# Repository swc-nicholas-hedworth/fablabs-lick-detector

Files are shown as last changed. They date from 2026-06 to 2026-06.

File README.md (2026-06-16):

# Fablabs Lick Detector

Inspired by the Allen Institute's: https://github.com/AllenNeuralDynamics/harp.device.lickety-split

## 1. Introduction

Capacitive lick detection offer advantages in the accuracy and speed of lick/touch detection. The challenge comes when using it with ephys devices such as the neuropixel which can pickup the input signal from the touch detector as noise. Our lick detector was inspired by the Allen Institutes lick detector which is shown to have low impact on ephys recordings.

The goals for this device were as follows:
- Reliable lick detection
- Low noise on ephys readings
- Simple to adjust and debug
- Easy to manufacture
- Easy to adapt into your own design

## 2. Setup
### Power Supply Requirements
- Min. Voltage = 3V
- Max. Voltage = 5.5V
- Max Current Consumption = 70mA (regardless of input voltage).

The output TTL depends on the input VCC voltage. For example:
- If VCC = 3.3V, output TTL amplitude = 3.3V
- If VCC = 5V, output TTL amplitude = 5V

### Ground Connection
Although not strictly necessary, it is encouraged for the mouse to have a reference to the board's ground potential. Basically the mouse needs to touch a conductor which is connected to the board's 

#### Metalic Floor
if the floor the mouse stands on is conductive, you may connect this floor to the ground potential.

#### Ephys
If the mouse has an implanted ephys device, it is posssible to connect the board's ground to that of the implant's ground.

### Spout Connection
Using crocodile clip

## 3. Calibration

This section outlines how to set the positions of the potentiometers RV1 and RV2 without any specialised equipment.

If any steps do not work, see the debugging guide.

### Step 0: Theory
RV1 is used to set the oscillators gain. clockwise increases the gain. The goal is to have the gain as low as possible to produce a low amplitude and clean signal to the spout so as to not intefere with ephys measurements. At maximum gain the signal will be distorted, introducing harmonics to the signal which is undesireable. At a certain "minimum" gain the oscillator will stop working. The goal is to have the oscillator just turn on, this gives us the lowest circuit noise.

RV2 is used to set the output gain. clockwise increases the gain. The goal is to have gain as low as possible to achieve extremely fast response to lick events. The output signal goes through a schmitt trigger, ensuring the gain sets the output at just the point the schmitt trigger activates ensures the quickest response times.

### Step 1: Initial conditions
- Turn RV1 all the way clockwise. (max oscillator gain)
- Turn RV2 all the way anticlockwise (min output gain)

This condition ensures that the oscillator is working (although distorted) and that the LED is on.

### Step 2: Detection
- Turn RV2 clockwise until the LED turns off.

You should see the LED turn on when you touch the "SPOUT" pin, and turn back off when you stop touching

### Step 3: Refine
**The following steps reduce the amplitude of the oscillator, thereby giving lower noise to ephys measurements.**

- Turn RV1 anticlockwise until the LED turns on.
- Turn RV2 clockwise until the LED turns back off.
- Test that touching the "SPOUT" pin still turns the LED on.

### Step 4: Repeat

- Repeat Step 3 until the LED seizes to turn off or if the LED starts behaving weirdly.
- When you reach the point that the LED starts behaving weirdly, revert RV1 and RV2 back to the previous state when the LED was still operating successfully.

## 4. Test Results

This section is intended to show the typical performance of the lick detector at each test point, showing how individual parts of the circuit should perform under normal conditions.

A Keysight DSOX1204A was used to capture the waveform and calculate the FFT. A custom BNC to pin header cable was created to feed signals from the board to the oscilloscope.

### [VCC] Input Voltage
The input voltage is used to power the dual supply converter on the board and the output stage op-amp (see amp and TTL test points).

### [V+] Positive Voltage Rail
This supply rail is generated by the dual supply converter.

### [V-] Negative Voltage Rail
This supply rail is generated by the dual supply converter.

### [osc] Oscillator

### [out] Signal to Spout

### [buf] Buffered Signal from Spout

### [hwr] Half Wave Rectifier

### [pfwr] Precision Full Wave Rectifier

### [lpf] Low-Pass Filter

### [amp] Amplifier 

### [TTL] Final Output TTL

### 5. EMI Performance

This section focuses on how the lick detectors near field noise looks like.

#### E-Field

#### H-Field

### 6. Impact on Ephys Recordings

This section evaluates the impact of noise on Ephys Recordings.

A mouse will lick from a spout. We will collect the following readings:
1. **Control**: 
2. **Grounded to Ephys**:
3. **Grounded to Ephys and Conductive Floor**:

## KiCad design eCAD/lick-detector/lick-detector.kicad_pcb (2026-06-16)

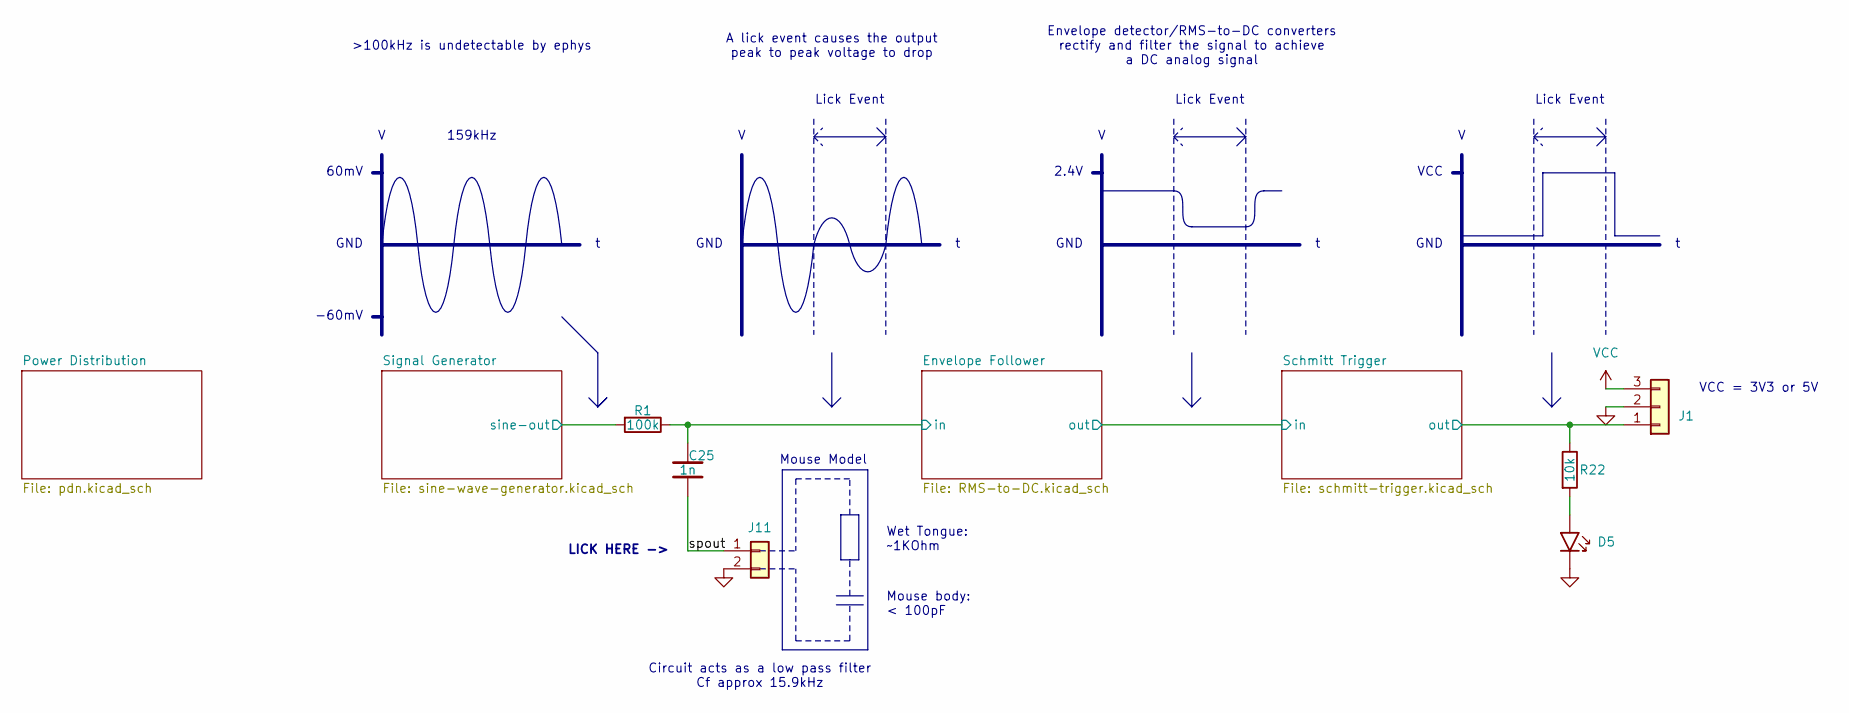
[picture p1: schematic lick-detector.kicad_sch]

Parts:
C25: 1n; C_0603_1608M; Part Version 0.0.0; JLCPCB Part # C1588
D5: !LED; LED_0805_2012M; Part Version 0.0.0; JLCPCB Part # C2297
J1: J_PinHeader_01x03_2.54_V; MFR.Part # PZ254V-11-03P; JLCPCB Part # C2937625
J11: J_PinHeader_01x02_2.54_V; MFR.Part # PZ254V-11-02P; JLCPCB Part # C492401
R1: 100k; R_0603_1608M; Part Version 0.0.0; JLCPCB Part # C25803
R22: 10k; R_0603_1608M; Part Version 0.0.0; JLCPCB Part # C25804

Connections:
/RMS-to-DC/in: C25.2, R1.2; also elsewhere on the board
/schmitt-trigger/out: J1.1, R22.2; also elsewhere on the board
/sine-wave-generator/out: R1.1; also elsewhere on the board
/spout: C25.1, J11.1
GND: D5.1 (K), J1.2, J11.2; also elsewhere on the board
unnamed: D5.2 (A), R22.1
VCC: J1.3; also elsewhere on the board

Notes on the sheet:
Lick Event
VCC
A lick event causes the output peak to peak voltage to drop
159kHz
GND
2.4V
>100kHz is undetectable by ephys
Wet Tongue: ~1KOhm
Mouse Model
-60mV
Envelope detector/RMS-to-DC converters rectify and filter the signal to achieve a DC analog signal
LICK HERE ->
VCC = 3V3 or 5V
Mouse body: < 100pF
Circuit acts as a low pass filter Cf approx 15.9kHz
60mV

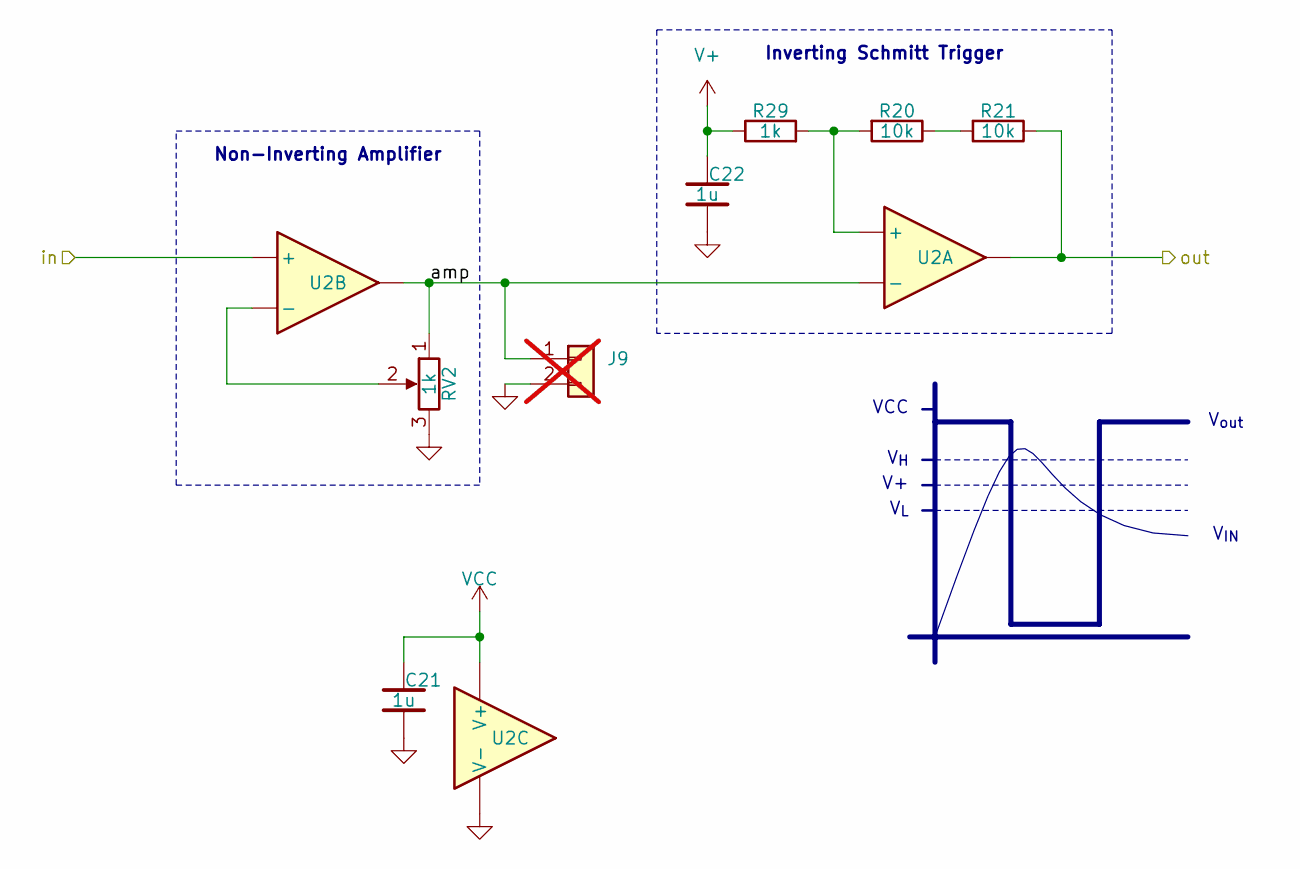
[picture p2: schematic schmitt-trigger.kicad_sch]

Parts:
C21, C22: 1u; C_0603_1608M; Part Version 0.0.0; JLCPCB Part # C15849
J9: J_PinHeader_01x02_2.54_V; MFR.Part # PZ254V-11-02P; JLCPCB Part # C492401; not fitted
R20, R21: 10k; R_0603_1608M; Part Version 0.0.0; JLCPCB Part # C25804
R29: 1k; R_0603_1608M; Part Version 0.0.0; JLCPCB Part # C22962
RV2: 1k; 3314J-1-102E; Part Version 0.0.0; JLCPCB Part # C124640
U2: OPA2365; SOIC-8_3.9x4.9mm; Part Version 0.0.0; JLCPCB Part # C130011

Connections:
/RMS-to-DC/lpf: U2.5 (+); also elsewhere on the board
/schmitt-trigger/amp: J9.1, RV2.1, U2.2 (-), U2.7
/schmitt-trigger/out: R21.2, U2.1; also elsewhere on the board
GND: C21.1, C22.1, J9.2, RV2.3, U2.4 (V-); also elsewhere on the board
unnamed: R20.2, R21.1
unnamed: R20.1, R29.1, U2.3 (+)
unnamed: RV2.2, U2.6 (-)
V+: C22.2, R29.2; also elsewhere on the board
VCC: C21.2, U2.8 (V+); also elsewhere on the board

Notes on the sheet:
V_{L}
V_{H}
VCC
V_{out}
V_{IN}
Inverting Schmitt Trigger
Non-Inverting Amplifier

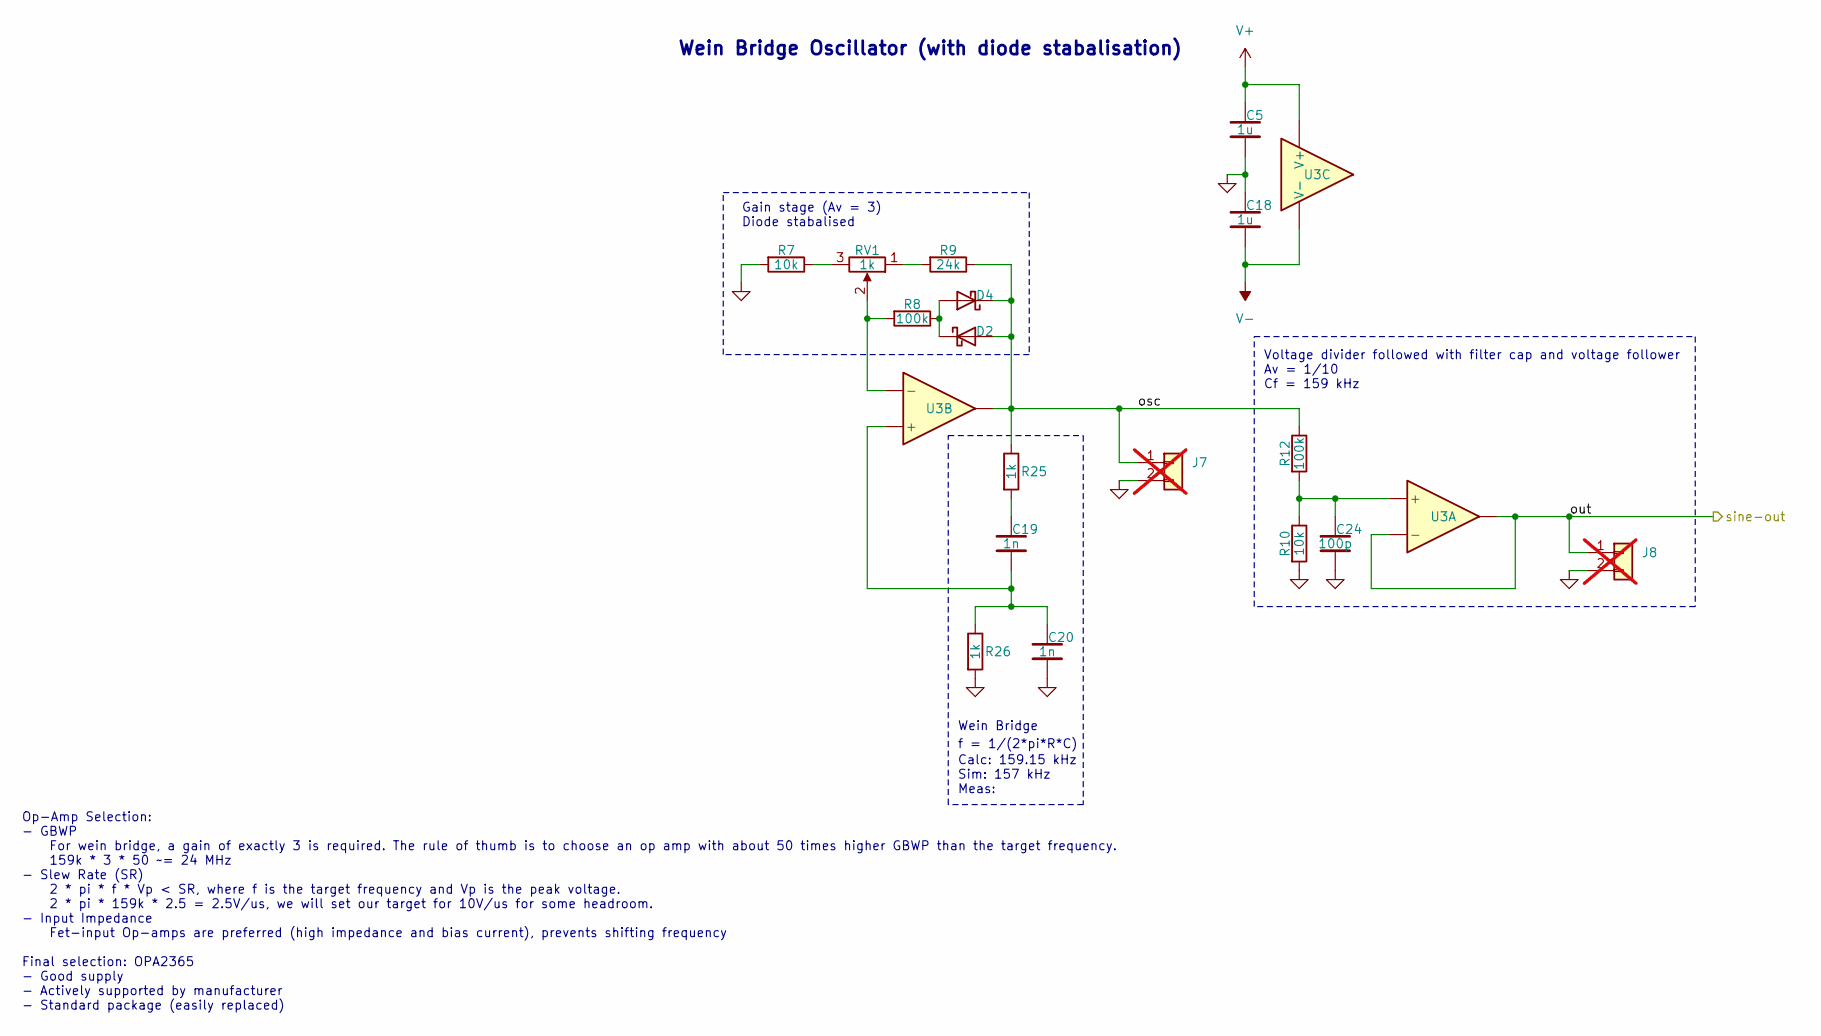
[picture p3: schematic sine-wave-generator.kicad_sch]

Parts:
C5, C18: 1u; C_0603_1608M; Part Version 0.0.0; JLCPCB Part # C15849
C19, C20: 1n; C_0603_1608M; Part Version 0.0.0; JLCPCB Part # C1588
C24: 100p; C_0603_1608M; Part Version 0.0.0; JLCPCB Part # C14858
D2, D4: BAT54; SOD-323; Part Version 0.0.0; JLCPCB Part # C21107
J7, J8: J_PinHeader_01x02_2.54_V; MFR.Part # PZ254V-11-02P; JLCPCB Part # C492401; not fitted
R7, R10: 10k; R_0603_1608M; Part Version 0.0.0; JLCPCB Part # C25804
R8, R12: 100k; R_0603_1608M; Part Version 0.0.0; JLCPCB Part # C25803
R9: 24k; R_0603_1608M; Part Version 0.0.0; JLCPCB Part # C23352
R25, R26: 1k; R_0603_1608M; Part Version 0.0.0; JLCPCB Part # C22962
RV1: 1k; 3314J-1-102E; Part Version 0.0.0; JLCPCB Part # C124640
U3: OPA2365; SOIC-8_3.9x4.9mm; Part Version 0.0.0; JLCPCB Part # C130011

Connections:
/sine-wave-generator/osc: D2.2 (A), D4.1 (K), J7.1, R9.2, R12.2, R25.2, U3.7
/sine-wave-generator/out: J8.1, U3.1, U3.2 (-); also elsewhere on the board
GND: C5.1, C18.2, C20.1, C24.1, J7.2, J8.2, R7.1, R10.1, R26.1; also elsewhere on the board
unnamed: C19.2, R25.1
unnamed: D2.1 (K), D4.2 (A), R8.2
unnamed: R7.2, RV1.3
unnamed: R9.1, RV1.1
unnamed: C24.2, R10.2, R12.1, U3.3 (+)
unnamed: C19.1, C20.2, R26.2, U3.5 (+)
unnamed: R8.1, RV1.2, U3.6 (-)
V+: C5.2, U3.8 (V+); also elsewhere on the board
V-: C18.1, U3.4 (V-); also elsewhere on the board

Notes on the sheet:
f = 1/(2*pi*R*C)
Gain stage (Av = 3) Diode stabalised
Calc: 159.15 kHz Sim: 157 kHz Meas:
Op-Amp Selection: - GBWP For wein bridge, a gain of exactly 3 is required. The rule of thumb is to choose an op amp with about 50 times higher GBWP than the target frequency. 159k * 3 * 50 ~= 24 MHz - Slew Rate (SR) 2 * pi * f * Vp < SR, where f is the target frequency and Vp is the peak voltage. 2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
Voltage divider followed with filter cap and voltage follower Av = 1/10 Cf = 159 kHz
Wein Bridge Oscillator (with diode stabalisation)
Wein Bridge

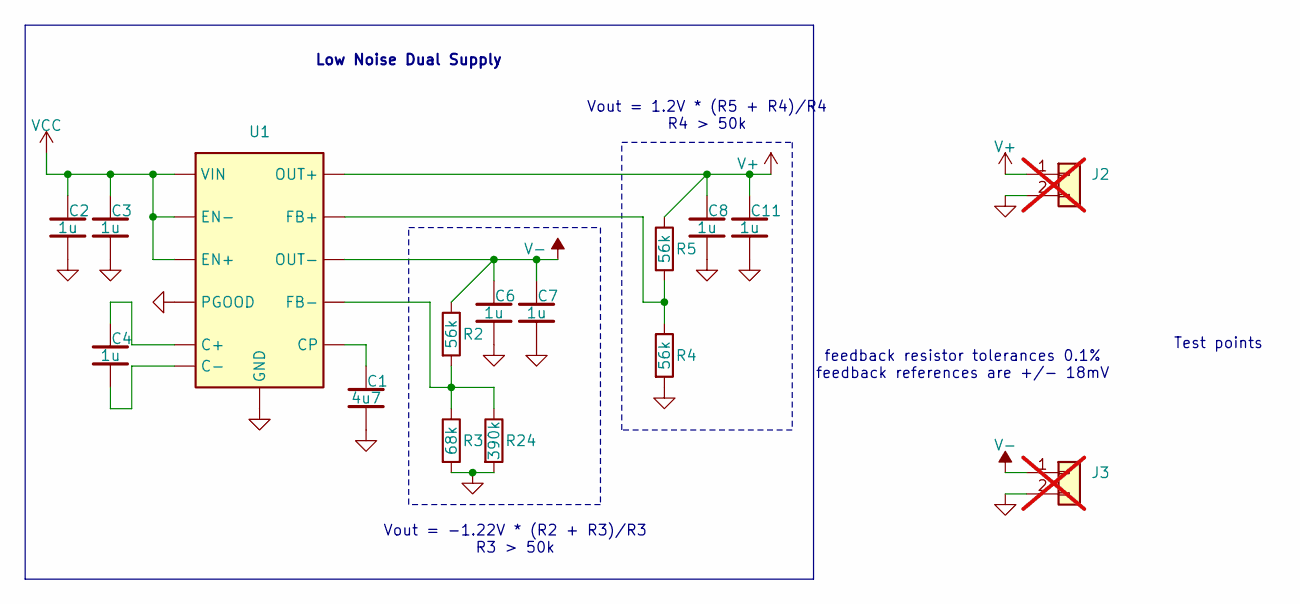
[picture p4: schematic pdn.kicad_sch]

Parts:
C1: 4u7; C_0603_1608M; Part Version 0.0.0; JLCPCB Part # C19666
C2, C3, C4, C6, C7, C8, C11: 1u; C_0603_1608M; Part Version 0.0.0; JLCPCB Part # C15849
J2, J3: J_PinHeader_01x02_2.54_V; MFR.Part # PZ254V-11-02P; JLCPCB Part # C492401; not fitted
R2, R4, R5: 56k; R_0603_1608M; Part Version 0.0.0; JLCPCB Part # C23206
R3: 68k; R_0603_1608M; Part Version 0.0.0; JLCPCB Part # C23231
R24: 390k; R_0603_1608M; Part Version 0.0.0; JLCPCB Part # C137735
U1: LM27762DSSR; WSON-12-EP; MFR.Part # LM27762DSSR; JLCPCB Part # C473398

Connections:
GND: C1.1, C2.1, C3.1, C6.1, C7.1, C8.1, C11.1, J2.2, J3.2, R3.1, R4.1, R24.1, U1.1 (PGOOD), U1.4 (GND), U1.13 (PAD); also elsewhere on the board
unnamed: C4.2, U1.10 (C+)
unnamed: C4.1, U1.9 (C-)
unnamed: C1.2, U1.5 (CP)
unnamed: R4.2, R5.1, U1.2 (FB+)
unnamed: R2.1, R3.2, R24.2, U1.7 (FB-)
V+: C8.2, C11.2, J2.1, R5.2, U1.11 (OUT+); also elsewhere on the board
V-: C6.2, C7.2, J3.1, R2.2, U1.6 (OUT-); also elsewhere on the board
VCC: C2.2, C3.2, U1.3 (VIN), U1.8 (EN-), U1.12 (EN+); also elsewhere on the board

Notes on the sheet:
Test points
feedback resistor tolerances 0.1% feedback references are +/- 18mV
Vout = 1.2V * (R5 + R4)/R4 R4 > 50k
Low Noise Dual Supply
Vout = -1.22V * (R2 + R3)/R3 R3 > 50k

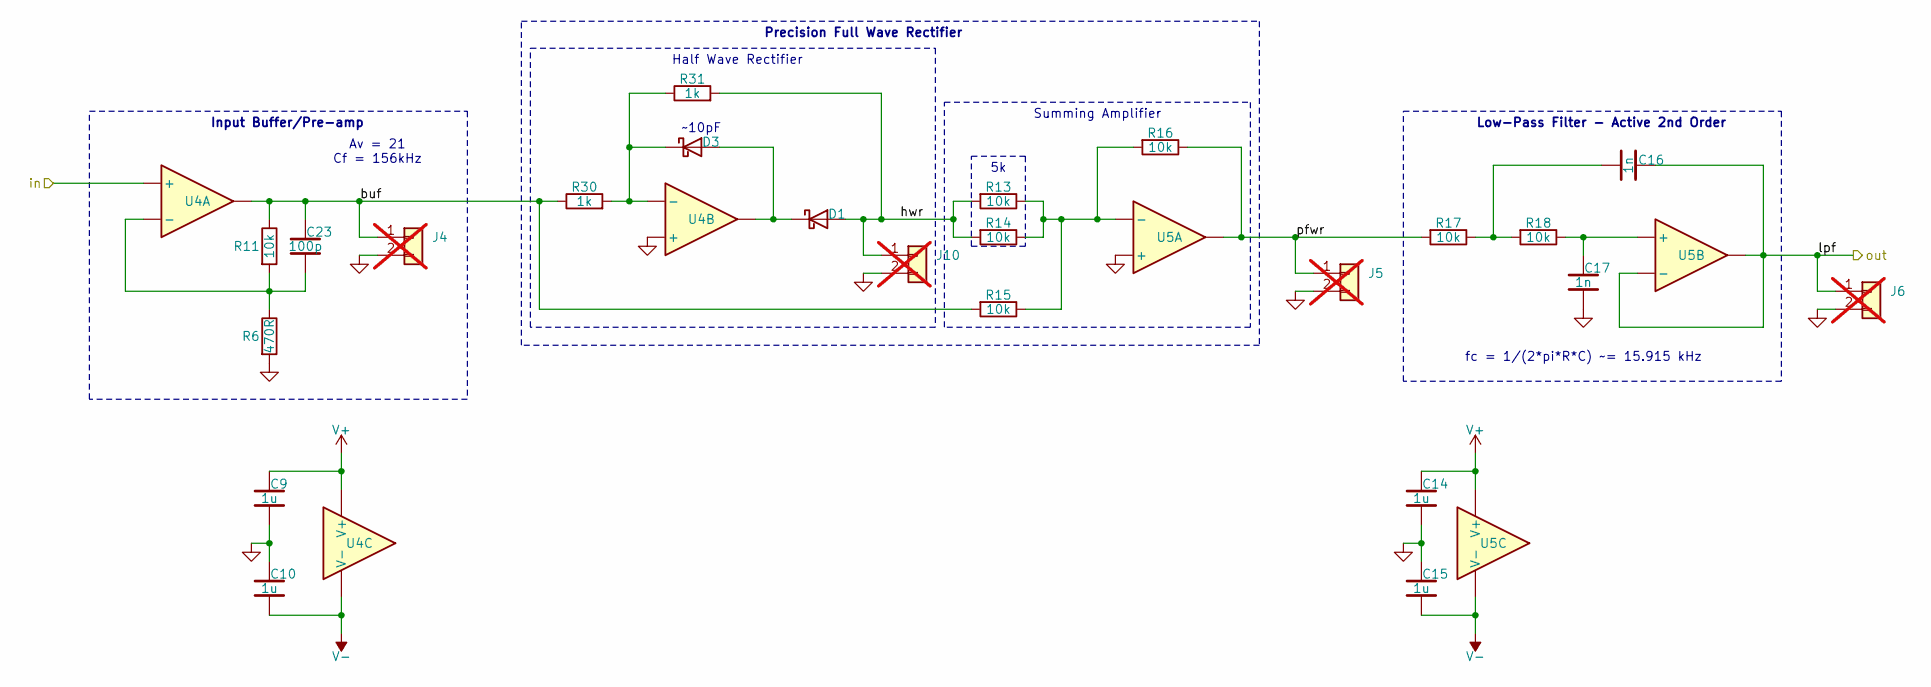
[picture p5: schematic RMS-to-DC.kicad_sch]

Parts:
C9, C10, C14, C15: 1u; C_0603_1608M; Part Version 0.0.0; JLCPCB Part # C15849
C16, C17: 1n; C_0603_1608M; Part Version 0.0.0; JLCPCB Part # C1588
C23: 100p; C_0603_1608M; Part Version 0.0.0; JLCPCB Part # C14858
D1, D3: BAT54; SOD-323; Part Version 0.0.0; JLCPCB Part # C21107
J4, J5, J6, J10: J_PinHeader_01x02_2.54_V; MFR.Part # PZ254V-11-02P; JLCPCB Part # C492401; not fitted
R6: 470R; R_0603_1608M; Part Version 0.0.0; JLCPCB Part # C23179
R11, R13, R14, R15, R16, R17, R18: 10k; R_0603_1608M; Part Version 0.0.0; JLCPCB Part # C25804
R30, R31: 1k; R_0603_1608M; Part Version 0.0.0; JLCPCB Part # C22962
U4, U5: OPA2365; SOIC-8_3.9x4.9mm; Part Version 0.0.0; JLCPCB Part # C130011

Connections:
/RMS-to-DC/buf: C23.2, J4.1, R11.2, R15.1, R30.2, U4.1
/RMS-to-DC/hwr: D1.2 (A), J10.1, R13.1, R14.1, R31.1
/RMS-to-DC/in: U4.3 (+); also elsewhere on the board
/RMS-to-DC/lpf: C16.2, J6.1, U5.6 (-), U5.7; also elsewhere on the board
/RMS-to-DC/pfwr: J5.1, R16.2, R17.1, U5.1
GND: C9.1, C10.2, C14.1, C15.2, C17.1, J4.2, J5.2, J6.2, J10.2, R6.1, U4.5 (+), U5.3 (+); also elsewhere on the board
unnamed: C16.1, R17.2, R18.1
unnamed: D1.1 (K), D3.2 (A), U4.7
unnamed: D3.1 (K), R30.1, R31.2, U4.6 (-)
unnamed: C23.1, R6.2, R11.1, U4.2 (-)
unnamed: R13.2, R14.2, R15.2, R16.1, U5.2 (-)
unnamed: C17.2, R18.2, U5.5 (+)
V+: C9.2, C14.2, U4.8 (V+), U5.8 (V+); also elsewhere on the board
V-: C10.1, C15.1, U4.4 (V-), U5.4 (V-); also elsewhere on the board

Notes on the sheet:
fc = 1/(2*pi*R*C) ~= 15.915 kHz
Low-Pass Filter - Active 2nd Order
Input Buffer/Pre-amp
Half Wave Rectifier
Summing Amplifier
~10pF
Precision Full Wave Rectifier
Av = 21 Cf = 156kHz

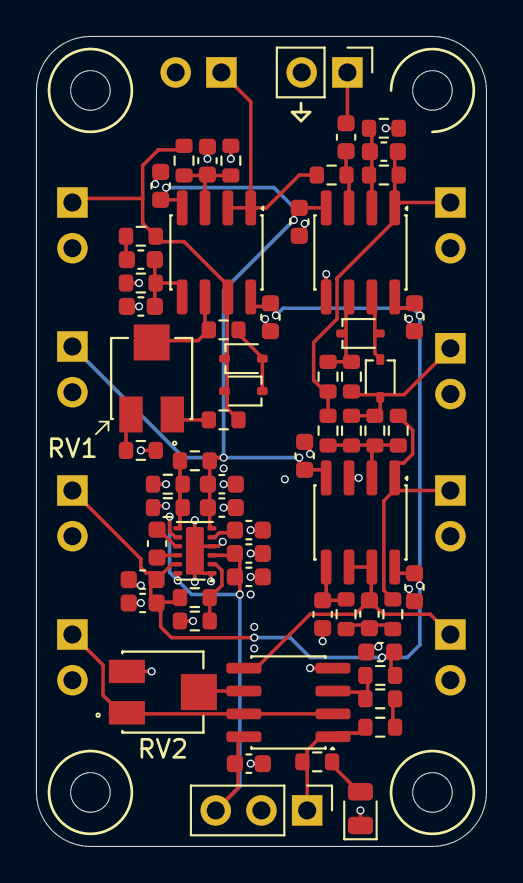
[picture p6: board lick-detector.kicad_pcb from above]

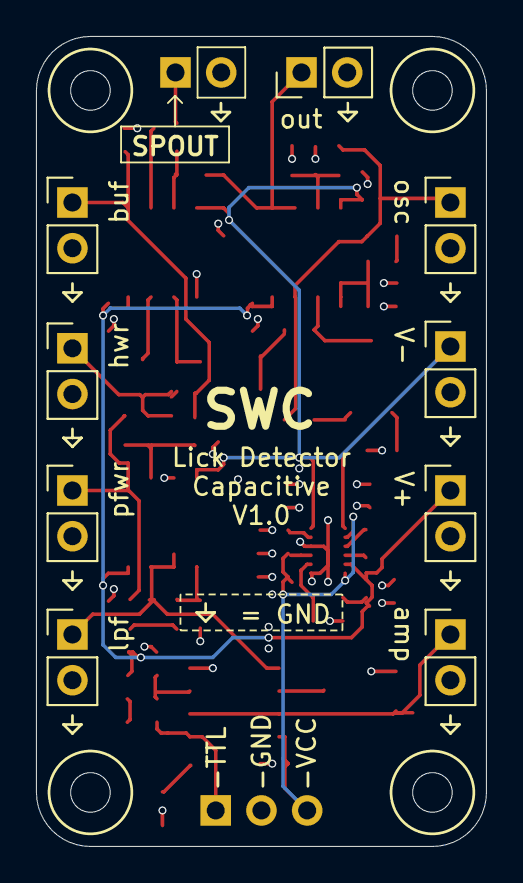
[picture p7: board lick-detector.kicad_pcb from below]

Board: 4 copper layers, 25.0 x 45.0 mm, 73 parts (9 on the bottom side), 36 nets.
